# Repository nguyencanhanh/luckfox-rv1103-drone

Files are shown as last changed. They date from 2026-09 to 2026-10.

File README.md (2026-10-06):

# Drone AI trên RV1103 (Luckfox Pico Mini B)

Nguyên mẫu quadcopter dùng **một chip Rockchip RV1103**:
- **Cortex-A7 chạy Linux:** camera, NPU nhận dạng, Wi-Fi, GPS, bộ thu RC.
- **Lõi MCU RISC-V (HPMCU) chạy RT-Thread:** vòng điều khiển bay 1 kHz.

Mục tiêu dự án là trả lời bằng số liệu đo được: **kiến trúc một chip có bay được không**. Nếu không, phương án B là thêm một MCU điều khiển bay rời.

> **Trạng thái (2026-09-27):** chưa bay thật.
> - Linux và MCU đã chạy song song trên board, vòng 1 kHz đã đo.
> - Phần mềm bay chạy đầy đủ trong mô phỏng và lái được trong 3D.
> - Mạch bay LFX_FC_R1 đã thiết kế xong, chưa sản xuất.
> - Chưa có driver cảm biến thật, chưa xuất PWM ra ESC. Motor chưa bao giờ được cấp lệnh.

Sơ đồ khối hệ thống

## Mục lục

- [Trạng thái theo mốc](#trạng-thái-theo-mốc)
- [Kiến trúc](#kiến-trúc)
- [Phần cứng: mạch bay LFX_FC_R2](#phần-cứng-mạch-bay-lfx_fc_r2)
- [Mô phỏng](#mô-phỏng)
- [Bắt đầu nhanh](#bắt-đầu-nhanh)
- [Cấu trúc repo](#cấu-trúc-repo)
- [An toàn](#an-toàn)
- [Tài liệu](#tài-liệu)
- [Nguồn tham khảo](#nguồn-tham-khảo)
- [License](#license)

## Trạng thái theo mốc

| Mốc | Nội dung | Kết quả | Bằng chứng |
|---|---|---|---|
| 01 | Điều tra phần cứng RV1103, HPMCU trong SDK | xong | [RV1103_MCU.md](docs/RV1103_MCU.md), [PERIPHERALS.md](docs/PERIPHERALS.md) |
| 02 | Build firmware Luckfox stock trên macOS | **PASS** | `logs/sdk_build.log`, [MILESTONE1.md](docs/MILESTONE1.md) |
| 03 | Build RT-Thread cho HPMCU | **PASS** | [MCU_BUILD.md](docs/MCU_BUILD.md) |
| 04 | MCU chạy song song Linux, vòng 1 kHz | **PASS trên board**: 2 × 1 000 000 vòng, 0 lỡ chu kỳ; jitter 18,2 µs lúc idle, 116,7 µs khi camera chạy | [REALTIME.md](docs/REALTIME.md) |
| — | Mạch bay LFX_FC_R1 (46 × 46 mm, 4 lớp) | thiết kế xong: ERC 0, DRC 0, 0 nối hở, khớp sơ đồ | [phần cứng](#phần-cứng-mạch-bay-lfx_fc_r1) |
| 05 | Phần mềm bay + mô phỏng SITL + 3D | **77/77 unit test, 10/10 kịch bản bay** (×2 profile cảm biến), kiểm thử bàn phím end-to-end 6/6 | [simulator/README.md](simulator/README.md) |
| 05b | Phần mềm bay chạy trên HPMCU với cảm biến giả (đo thời gian) | build xong (53 KB), **chưa chạy**: board chưa cắm | `tools/run_fc_mcu.sh` |
| 06–07 | Driver SPI + ICM-42688-P trên MCU | chưa làm: cần module IMU để kiểm | |
| 11 | Xuất PWM / DShot, đo bằng logic analyzer | chưa làm, **không gắn cánh** | |
| 12–13 | Điều khiển từ xa: IPC Linux ↔ MCU, `rc-bridge` (ELRS + mạng), trạm mặt đất có camera | **code xong, chuỗi đầy đủ chạy trên Mac 7/7**; build cho board xong, **chưa chạy trên board**; bộ thu ELRS cần chuyển console khỏi UART2 | [ground/README.md](ground/README.md) |
| M3 | Camera → NPU → nhận dạng, Wi-Fi, telemetry | chưa làm | |

Kế hoạch đầy đủ theo thứ tự an toàn ở mục [An toàn](#an-toàn).

## Kiến trúc

| Miền | Chạy gì | Sở hữu phần cứng |
|---|---|---|
| **HPMCU** RISC-V SCR1 297 MHz, `rv32imc` (không FPU), RT-Thread | vòng tốc độ quay 1 kHz, vòng góc 250 Hz, vòng độ cao 100 Hz, trộn motor, ARM / failsafe | SPI0 (IMU, barometer), PWM2 kênh 8–11 (4 ESC) |
| **Cortex-A7** 1,1 GHz, Linux (Buildroot của SDK) | đọc bộ thu RC (CRSF), camera + NPU, điều hướng, LTE + GPS (module Lierda), telemetry Wi-Fi, nạp firmware MCU và Lierda | UART2 (bộ thu RC), UART3 (Lierda: AT, GNSS, nạp firmware), chân 18/20 (RESET/BOOT Lierda), MIPI CSI, USB, SARADC, CRU |
| **DDR chung** 64 MB | MCU chạy ở `0x01800000` (256 KB, đã kiểm chứng); IPC đề xuất ở `0x01840000` | [MEMORY_MAP.md](docs/MEMORY_MAP.md) |

Luồng điều khiển:

```
IMU 1 kHz ─► hiệu chuẩn ─► lọc ─► Mahony (góc) + baro/accel (độ cao)
          ─► PID góc / độ cao ─► PID tốc độ quay ─► trộn quad-X ─► 4 motor (0..1)
tay điều khiển ELRS ─► bộ thu (CRSF 420 kbaud) ─► Linux ─► IPC ─► MCU (lệnh lái, ARM, chế độ)
```

Code bay (`mcu/`) là C99 thuần, chỉ dùng float, không cấp phát động. Cùng một mã nguồn build cho:
- máy Mac (mô phỏng);
- MCU (RT-Thread).

Chỗ đổi duy nhất là nguồn dữ liệu cảm biến:
- `SIM_SENSOR`: cảm biến giả trong mô phỏng;
- `REAL_SENSOR`: driver thật (bước 06–07).

Chi tiết và rủi ro: [ARCHITECTURE.md](docs/ARCHITECTURE.md), [architecture.html](docs/architecture.html).

**Rủi ro lớn nhất của kiến trúc một chip:**

| Rủi ro | Hệ quả |
|---|---|
| HPMCU không có FPU | code bay chạy bằng soft-float; phải đo thời gian thật |
| HAL MCU của RV1106 không có SPI và UART | phải tự viết driver |
| Tải camera làm jitter MCU tăng 6,4 lần | ảnh hưởng độ ổn định vòng điều khiển |
| Tín hiệu RC đi qua Linux | Linux treo là mất RC; MCU phải tự vào failsafe |

## Phần cứng: mạch bay LFX_FC_R2

**Một board 50 × 50 mm** gồm mạch bay cho Luckfox Pico Mini B và module **LTE Cat.1 bis + GNSS** (Lierda NT26-KCN E, khay nano-SIM, 2 cổng U.FL). Thiết kế bằng pipeline KiCad 10 viết bằng script, trong [`hardware/LFX_FC_R2/`](hardware/LFX_FC_R2): `design.py` → sơ đồ → PCB → file sản xuất.

| Mặt trên | Mặt dưới | 3D |
|---|---|---|
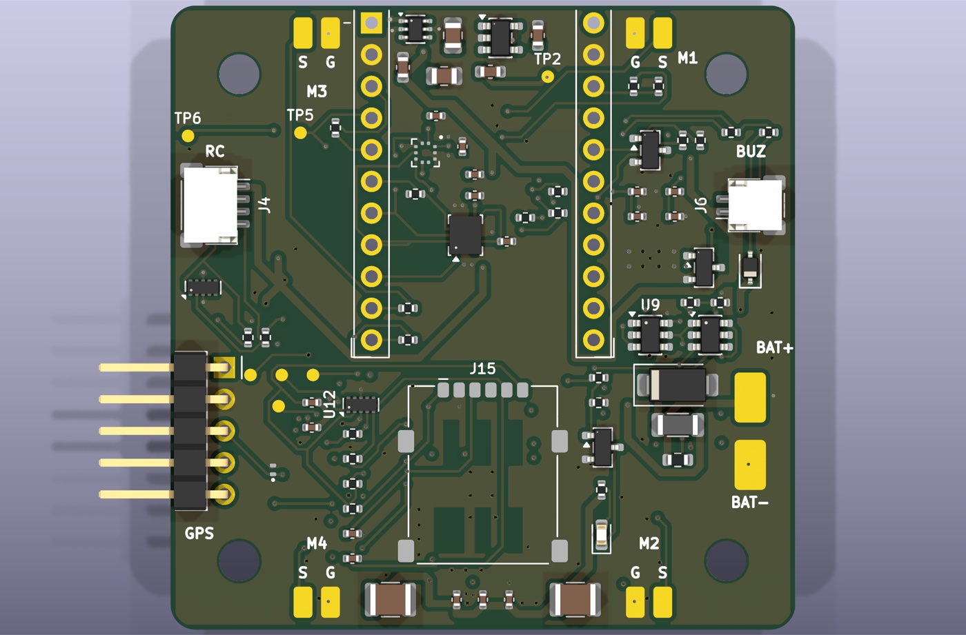
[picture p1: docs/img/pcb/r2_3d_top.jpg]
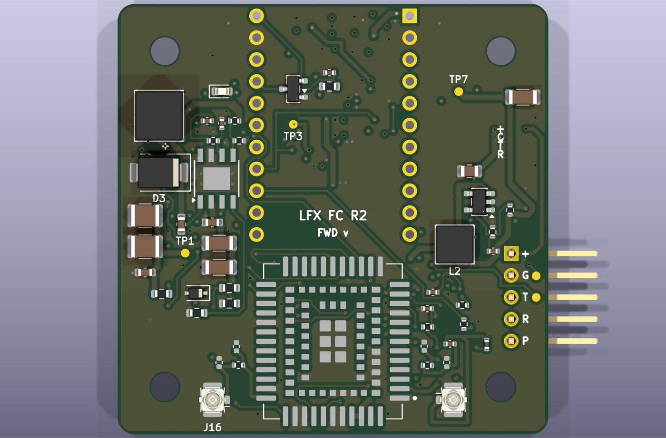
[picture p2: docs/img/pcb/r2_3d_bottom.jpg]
bottom
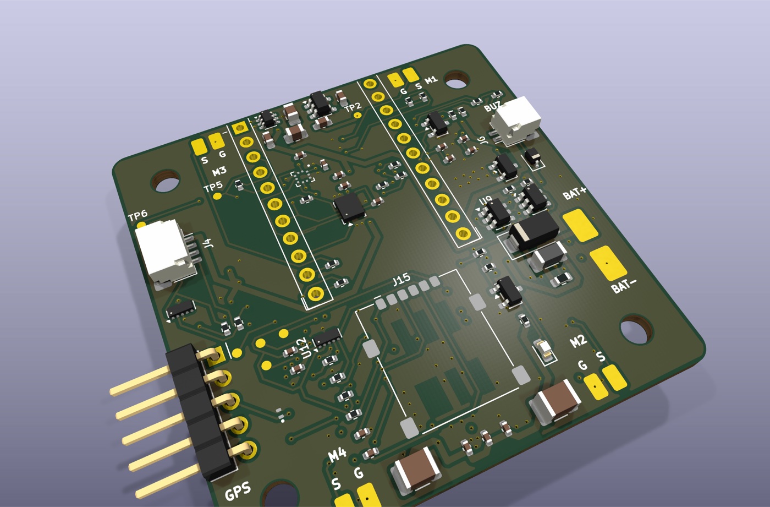
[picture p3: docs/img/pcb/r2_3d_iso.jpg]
iso
|  |  |  |

Module Lierda và đế cắm Luckfox chưa có mô hình 3D trong KiCad nên trên ảnh render chỉ thấy pad của chúng.

**Thông số:**
- **Kích thước:** 50 × 50 mm, 4 lớp: F.Cu tín hiệu / GND / VSYS (+ đảo 3,3 V cảm biến, đảo 3,8 V dưới module LTE, đảo GND dưới đường anten) / B.Cu.
- **Lỗ bắt vít:** 4 lỗ M3, khoảng cách lỗ **39 × 39 mm**, cách mép 5,5 mm.
- **Nguồn vào:** pin 2S–6S, hàn vào pad BAT+ / BAT− (mặt trên, phía trước bên phải).
- **Mạch nguồn:**
  - TVS SMAJ33A và ferrite chặn xung, lọc nhiễu.
  - Buck TPS54360 ra 5 V (theo thiết kế mẫu TI SLVSBB4G), ngưỡng UVLO 6,44 V. Đặt ở mặt dưới dải phải, cách IMU khoảng 15 mm, có lớp GND In1 ở giữa.
  - Diode lý tưởng LM66100 cấp VSYS cho Luckfox; LDO TLV75533 cấp 3,3 V riêng cho cảm biến.
  - Buck TLV62569 hạ +5 V xuống **3,8 V** cho module LTE. VBAT của module chỉ chịu 3,3–4,5 V, nên không lấy thẳng từ pin.
- **Cảm biến trên SPI0:** IMU ICM-42688-P và barometer BMP390, đặt dưới Luckfox; 4 đường SPI của IMU vẽ tay, không dùng via.
- **GPS ngoài (thêm 2026-10-04):** chân 14 (GPIO1_D2) thành **UART5_RX** cho cổng J18; chân chọn chip của barometer chuyển sang chân 15 (GPIO1_D3, MCU điều khiển như GPIO), bỏ chân ngắt dự phòng của IMU (IMU đọc kiểu polling). GNSS trong module Lierda vẫn giữ nguyên.
- **Motor:** 4 cặp pad S/G ở 4 góc cho **4 ESC rời** (PWM8–11, điện trở 47 Ω). Không còn cổng ESC 4-in-1.
- **LTE + GNSS: Lierda NT26-KCN E** ở mặt dưới, nửa trước. Khi đặt mua chọn bản **GPS + BDS**: bản NT26KCNE20GNB trong sổ tay phần cứng chỉ có BeiDou, chân ra giống hệt.
  - UART3 của Luckfox (chân 12/13) đi qua 2 con SN74LVC1T45 để chuyển 3,3 V ↔ 1,8 V. Chip này tự cách ly khi module tắt, vì UART của module không chịu điện áp ngược. Cùng một UART dùng cho lệnh AT, đọc GNSS và nạp firmware (921600 bd).
  - **Luckfox nạp firmware cho Lierda:** chân 18 kéo RESET_N qua MOSFET; chân 20 (GPIO4_C1, bank 1,8 V, cùng mức với module) nối USB_BOOT qua 1 kΩ. Giữ BOOT mức cao rồi reset ≥ 300 ms là module vào chế độ nạp. Có test pad USB (D+/D−/VBUS) để nạp cứu bằng máy tính.
  - Khay **nano-SIM** có nắp bản lề ở mặt trên, giữa phía trước; điện trở 22 Ω, tụ 33 pF, chống ESD TPD4E05U06.
  - 2 cổng U.FL ở 2 góc trước mặt dưới: GNSS bên trái, LTE bên phải. Đường 50 Ω rộng 0,35 mm trên B.Cu, có mạch π để chỉnh phối hợp trở kháng. GNSS cấp nguồn 3,3 V cho anten active; dùng anten thụ động thì bỏ R43.
  - Còi được điều khiển từ chân AGPIO5 (pad 97, ở mép module) của Lierda, vì Luckfox đã hết chân.
  - **Không bật chế độ ngủ của module** (`AT+QSCLK=1`): khi ngủ, VDD_EXT tắt nên bộ chuyển mức cách ly, Luckfox không đánh thức được qua UART.

**Đầu cắm và pad:**

| Cổng | Chân | Ghi chú |
|---|---|---|
| J2 / J3 · pad pin | BAT+ / BAT− | dây XT30 từ pin, cùng dây cấp cho 4 ESC |
| J4 · bộ thu RC ELRS | 1 5 V, 2 GND, 3 TX board → RX bộ thu, 4 RX board ← TX bộ thu | UART2, CRSF; R24 1 kΩ kéo lên để bộ thu không kẹt bootloader |
| J6 · còi | 1 +5 V, 2 còi − (MOSFET đóng ngắt) | gate do AGPIO5 của Lierda điều khiển |
| **J18 · module GPS ATGM336H** | 1 VCC +5 V, 2 GND, 3 TXD module → RX board, 4 RXD (không nối), 5 PPS (không nối) | header 2,54 mm 5 chân nằm ngang ở mép trái, **cùng thứ tự chân với module ATGM336H 5 chân**: thân nhựa trên board, chân cong chìa ra ngoài mép để cắm dây Dupont 5 sợi thẳng sang module (lọt dưới vỏ canopy). UART5 chỉ nhận (chân 14), NMEA 9600 mặc định; RXD và PPS bỏ trống vì Luckfox hết chân. Chống ESD TPD1E05U06 + 33 Ω. +5 V lấy từ buck TPS54360 (cùng nguồn với bộ thu RC J4, đường mặt dưới sát mép trái), nên GPS chỉ có điện khi cắm pin, không chạy khi chỉ cắm USB |
| J7–J14 · pad ESC | S / G ở 4 góc | M1 sau-phải, M2 trước-phải, M3 sau-trái, M4 trước-trái (Betaflight) |
| J15 · nano-SIM | | GCT SIM8060, nắp bản lề |
| J16 · U.FL LTE / J17 · U.FL GNSS | | mặt dưới, 2 góc trước |
| TP1–TP3, TP5, TP6 | +5 V, VSYS, +3V3S, RC_TX, RC_RX | TP5/TP6: xem console khi rút bộ thu |
| TP7–TP13 | +3V8, VDD_EXT 1,8 V, USB D+, USB D−, USB VBUS, DBG TX, DBG RX của Lierda | nạp cứu / xem log module |

**Kiểm tra:** ERC 0, DRC 0 vi phạm / 0 cảnh báo, 0 nối hở, 0 lỗi khớp sơ đồ (`--schematic-parity`).

**Bộ file sản xuất** (Gerber, khoan, BOM, vị trí linh kiện, STEP) do `make_fab.py` tạo ra `fab/`. Thư mục này không lưu trong git.

**Cần làm trước khi đặt hàng:**
- BOM chưa có mã linh kiện cụ thể (MPN).
- Nên chọn xi **ENIG**: IMU, barometer là chip chân LGA và module Lierda là LCC + LGA 109 chân, cần pad phẳng.

### Lắp drone: khung LFX_FRAME_R1, động cơ không chổi than, 4 ESC rời

| Khung (in 3D) | Lắp đủ: khung + board + vỏ + motor + ESC + pin | Nhìn từ trên |
|---|---|---|
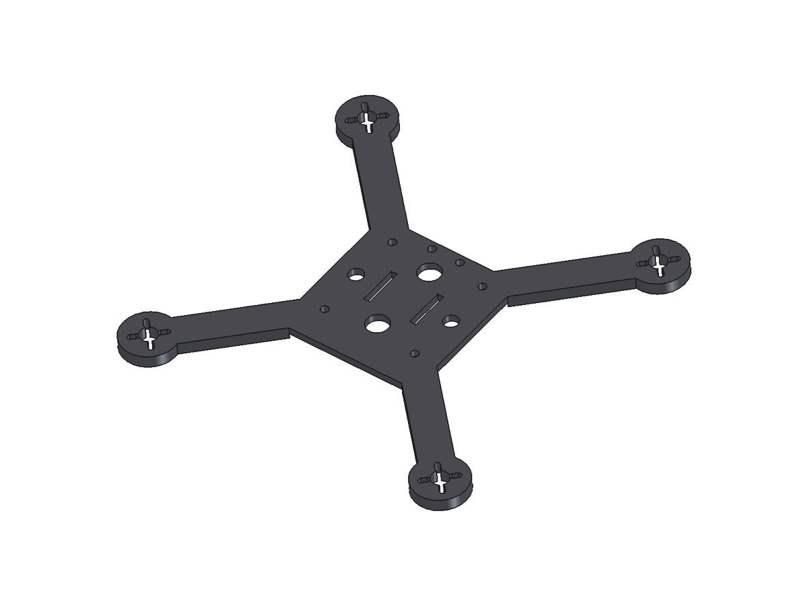
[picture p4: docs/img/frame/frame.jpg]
frame
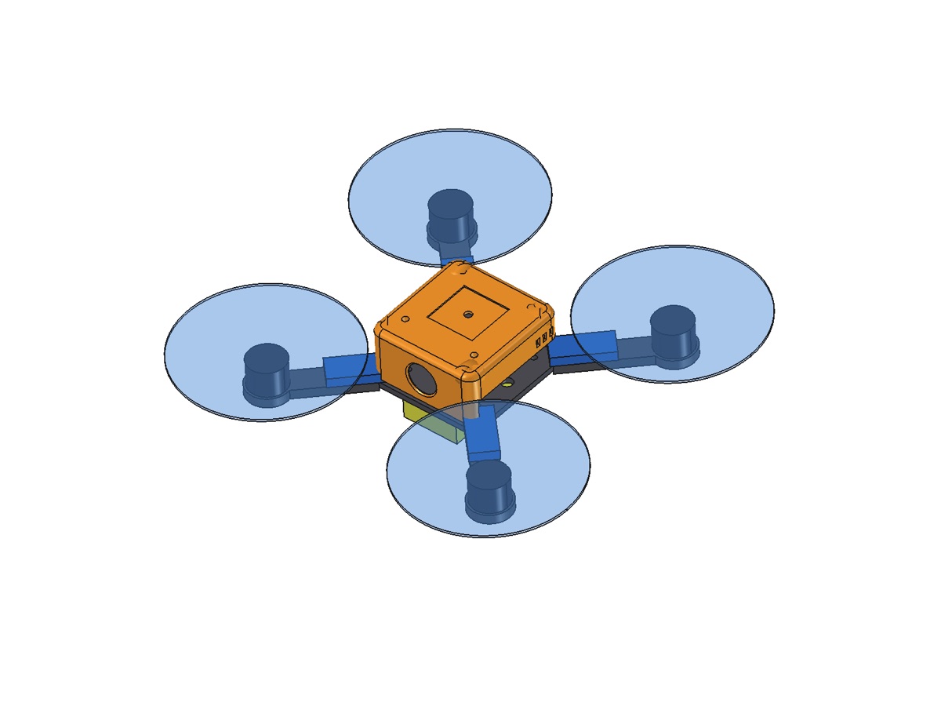
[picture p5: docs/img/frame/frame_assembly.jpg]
assembly
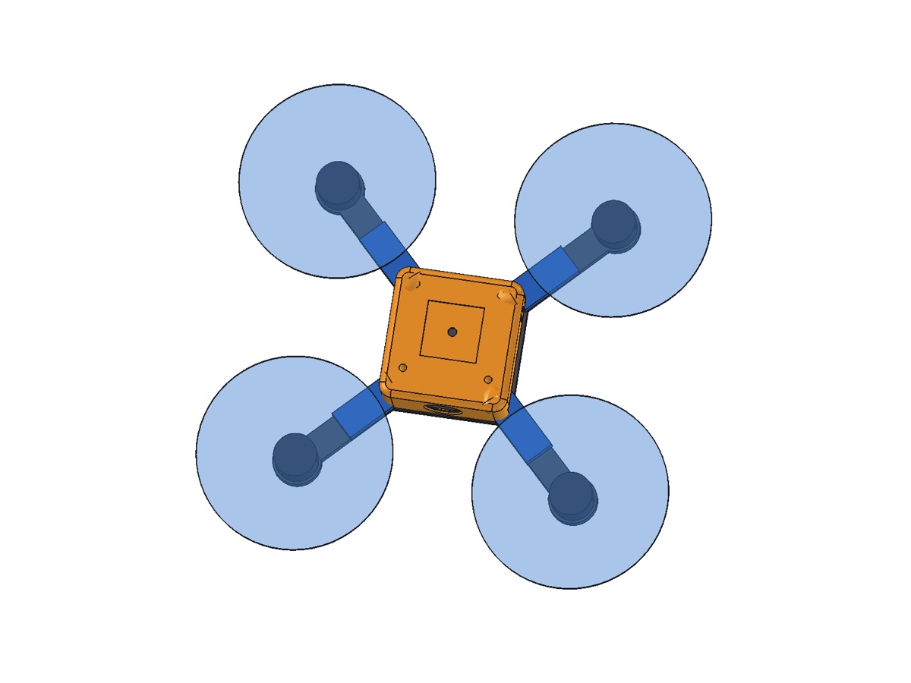
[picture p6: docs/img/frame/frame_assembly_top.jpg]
|  |  |  |

**Khung [`hardware/LFX_FRAME_R1`](hardware/LFX_FRAME_R1)** dựng bằng FreeCAD (script tham số `frame_freecad.py`), in 3D, cho **motor 1503 + cánh 3,5"**:
- Tấm giữa dày 3 mm: board bắt thẳng bằng **4 cột M3 dài 8 mm** vào lỗ 39 × 39, không cần tấm chuyển. Có 2 khe dây buộc pin 15 mm, lỗ khoét giảm nhẹ, 2 lỗ phía sau để buộc ống anten. Mặt dưới tấm giữa phẳng để kê pin.
- 4 tay đòn kiểu X, dày 5 mm, rộng 13 mm. Đế motor Ø22 mm có **rãnh M2 hướng tâm** (bán kính 4,3–6,6 mm): lắp được motor 1503 (4 × M2 theo hình vuông 9 × 9 mm) và các motor có lỗ trên vòng Ø9 mm. Lỗ giữa Ø7 mm cho trục và phe gài.
- **Khoảng cách motor do script tự tìm:** đẩy dần motor ra xa cho tới khi cánh 3,5" (thêm 2 mm dự phòng) không chạm vỏ canopy. Kết quả: motor cách tâm 63 mm theo mỗi trục (đường chéo trục 178 mm), khung 148 × 148 mm.
- 4 ESC buộc dây rút lên tay đòn, nằm ngoài vỏ; pin buộc dưới tấm giữa.
- In: PETG (hoặc PLA-CF), 5 lớp viền, infill 40 %. Khối lượng đặc khoảng 34 g.
- Đổi motor hoặc cánh: sửa `PROP_D`, `MOTOR_D`, `MOTOR_SLOT` ở đầu `frame_freecad.py` rồi chạy lại trong FreeCAD; khoảng cách motor tự tính lại.

**Linh kiện mua thêm:**

| Linh kiện | Gợi ý | Ghi chú |
|---|---|---|
| Motor ×4 | 1503, bản KV dành cho cánh 3,5" và đúng số cell pin (người bán thường ghi "3.5 inch 3S" hoặc "4S") | khoảng 8–9 g/con; 4 × M2 lỗ 9 × 9 mm |
| ESC ×4 | ESC rời 20–30 A, BLHeli_S / BLHeli_32 / AM32, chịu 2–4S | 1503 + cánh 3,5" kéo dòng cao hơn hẳn 1103, ESC 12 A không đủ |
| Cánh | 3,5" (3520 / 3525, 2–3 lá), lỗ trục hợp motor | |
| Pin | LiPo 3S hoặc 4S 450–650 mAh, đầu XT30 | |
| Cột M3 | 4 × 8 mm (khung → board) | |
| Anten | LTE dạng dán (FPC) + GNSS 25 × 25 mm (active 3,3 V hoặc thụ động), đầu U.FL | anten GNSS đặt trong hốc trên nóc vỏ |

**Đấu nối:**
```
Pin 3S/4S ─ XT30 ─┬─ nguồn 4 ESC (đỏ / đen)
                  └─ BAT+ / BAT− (J2 / J3) trên board
ESC n: tín hiệu → pad S, mass tín hiệu → pad G ở góc của motor n
   M1 sau-phải J7/J11 · M2 trước-phải J8/J12 · M3 sau-trái J9/J13 · M4 trước-trái J10/J14
Motor: 3 dây vào ESC; quay ngược chiều thì đổi 2 dây bất kỳ
```
- Board chạy 2S–6S (buck 5 V khởi động từ 6,44 V), nên 3S và 4S đều dư.
- ESC rời không có chân báo dòng, nên chỉ đo được áp pin (ADC_VBAT), không đo được dòng.

**Trọng lượng ước tính** (chưa cân thực tế):
- Board R2 khoảng 16 g, Luckfox + camera khoảng 8 g, 4 ESC khoảng 24 g, 4 motor 1503 khoảng 36 g, khung khoảng 34 g, vỏ khoảng 13 g, cánh khoảng 6 g, anten + ốc + dây khoảng 8 g, pin 4S 450 mAh khoảng 55 g (3S khoảng 40 g).
- Tổng **khoảng 200 g với 4S** (khoảng 185 g với 3S).
- Theo [bảng tra của Oscar Liang](https://oscarliang.com/table-prop-motor-lipo-weight/), cánh 3–3,5" với motor cỡ 1404–1505 trên 3S–4S hợp drone nặng khoảng 150–300 g, nên cấu hình này nằm giữa dải, dư lực. Mình chưa có số đo lực đẩy cụ thể của 1503; hãy xem bảng lực đẩy của đúng mẫu motor khi mua.

### Vỏ in 3D: LFX_CANOPY_R1

| Vỏ | Nhìn xuyên (kiểm tra lắp) | Phía sau |
|---|---|---|
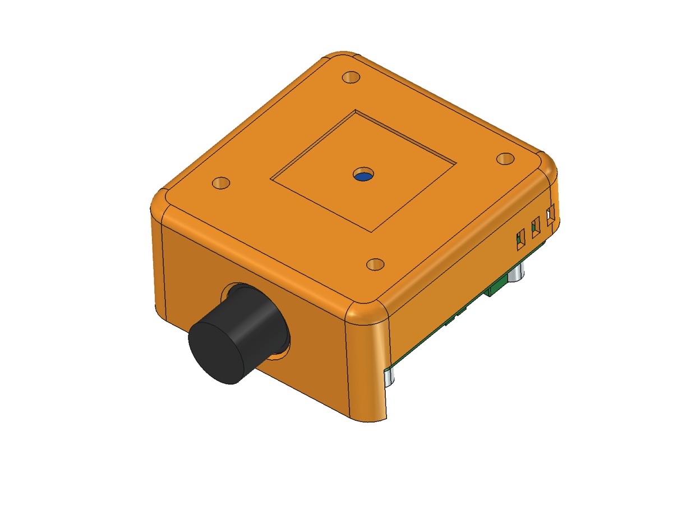
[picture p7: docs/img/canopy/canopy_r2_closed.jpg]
canopy
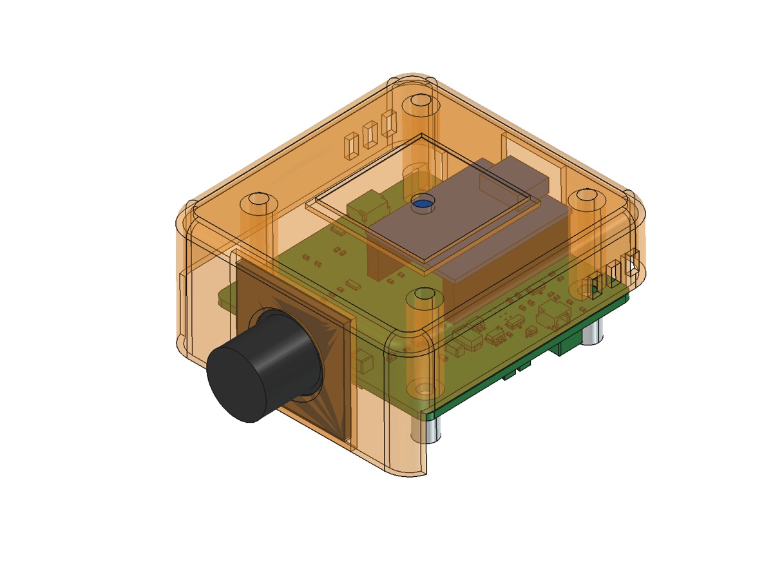
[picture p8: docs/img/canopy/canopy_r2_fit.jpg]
fit
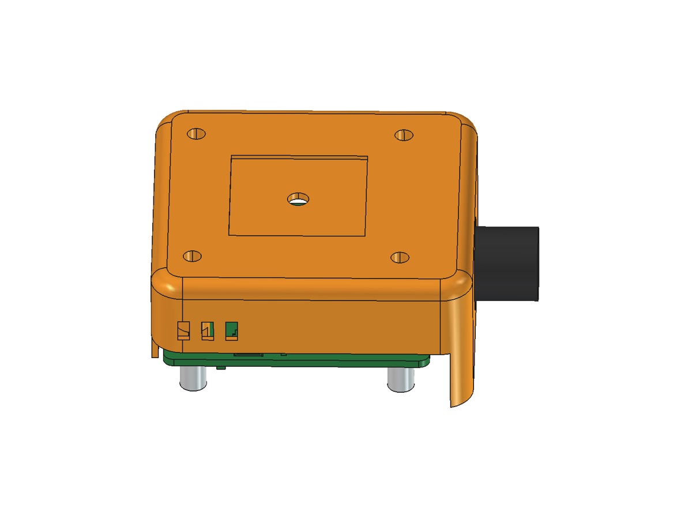
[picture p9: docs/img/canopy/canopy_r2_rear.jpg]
rear
|  |  |  |

Vỏ che board, dựng bằng **FreeCAD 1.1** (script tham số [`canopy_freecad.py`](hardware/LFX_CANOPY_R1/canopy_freecad.py), chạy trong FreeCAD hoặc qua addon [freecad-mcp](https://github.com/neka-nat/freecad-mcp)). Script dựng cả cụm lắp ráp từ file STEP của board (KiCad) cộng khối đại diện cho Luckfox, camera, Lierda, cột đỡ, rồi **kiểm tra va chạm**: không chạm.

- File in: [`canopy.stl`](hardware/LFX_CANOPY_R1/canopy.stl) (và `canopy.step`), 58 × 60 × 29 mm, khoảng 13 g PETG.
- Thành 1,2 mm (3 lớp viền với đầu phun 0,4 mm), bo tròn mọi cạnh, lỗ ống kính vát mép.
- Camera SC3336 áp vào mặt trong thành trước, có gờ định vị 4 phía; cố định bằng băng dính 2 mặt hoặc keo nến.
- Lỗ USB-C phía sau, nên **vẫn cắm cáp nạp code cho Luckfox khi đã đậy vỏ**.
- Hai bên hông để trống phía dưới cho dây RC, còi, ESC, dây pin và cáp U.FL; khe thông gió ngay trên Luckfox.
- Trên nóc có hốc lõm 0,8 mm đặt anten GNSS loại 25 × 25 mm (nằm trên cùng, nhìn thẳng lên trời) và lỗ luồn cáp; mặt nóc vẫn phẳng để in úp.
- 4 trụ rỗng tì xuống board tại 4 lỗ 39 × 39; vít **M3 × 25** xuyên trụ, qua board, vào cột đỡ.
- In: úp nóc xuống bàn in, PETG, không cần support.
- Sửa kích thước: đổi tham số đầu file `canopy_freecad.py` rồi chạy lại trong FreeCAD. File STEP của board xuất bằng `kicad-cli pcb export step` vào `hardware/LFX_CANOPY_R1/step/`.

### Phiên bản cũ

Vẫn giữ trong repo, DRC sạch, nhưng không còn là thiết kế chính:
- [`LFX_FC_R1`](hardware/LFX_FC_R1): mạch bay 46 × 46 mm, cổng ESC 4-in-1 (J1), cổng J5 nối sang board LTE ([ảnh](docs/img/pcb/3d_iso.jpg)).
- [`LFX_LTE_R1`](hardware/LFX_LTE_R1): board LTE 46 × 46 mm xếp tầng trên R1 ([ảnh](docs/img/pcb/lte_3d_iso.jpg)).
- [`LFX_MOUNT_R1`](hardware/LFX_MOUNT_R1): tấm chuyển lỗ 39 × 39 → khung 20 × 20 / 25,5 × 25,5 mm, dùng khi lắp board lên khung mua sẵn thay cho LFX_FRAME_R1 ([ảnh](docs/img/pcb/mount_3d_iso.jpg)).

## Mô phỏng

Toàn bộ phần mềm bay chạy trên máy Mac, lái được bằng bàn phím hoặc tay điều khiển USB. Tín hiệu điều khiển đi qua đúng đường mà bộ thu thật sẽ đi: khung CRSF → bộ đọc CRSF → `fc_tick()`. Chi tiết: [simulator/README.md](simulator/README.md).

| | |
|---|---|
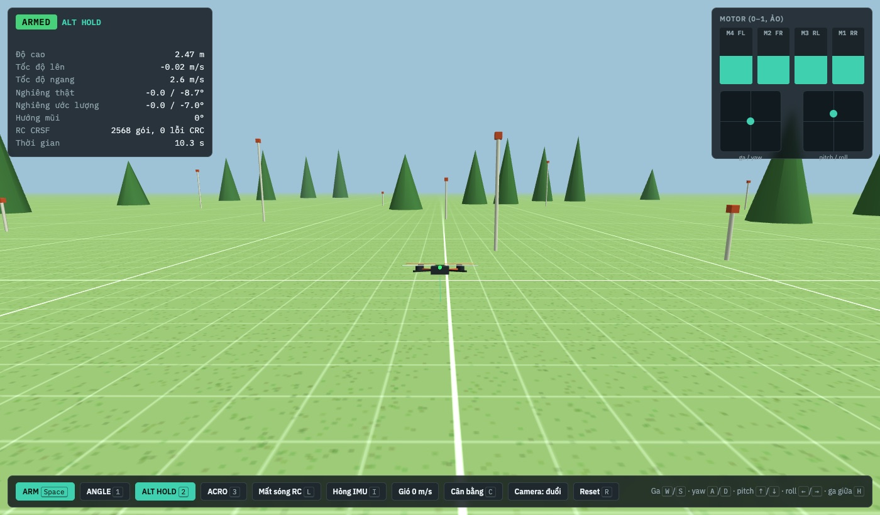
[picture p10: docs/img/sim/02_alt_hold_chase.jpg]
Giữ độ cao
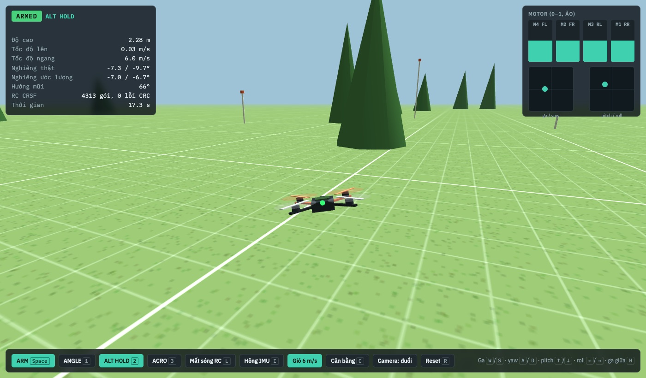
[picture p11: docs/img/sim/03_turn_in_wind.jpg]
Gió
|  **ALT HOLD**, camera đuổi theo |  Vòng trong gió 6 m/s |
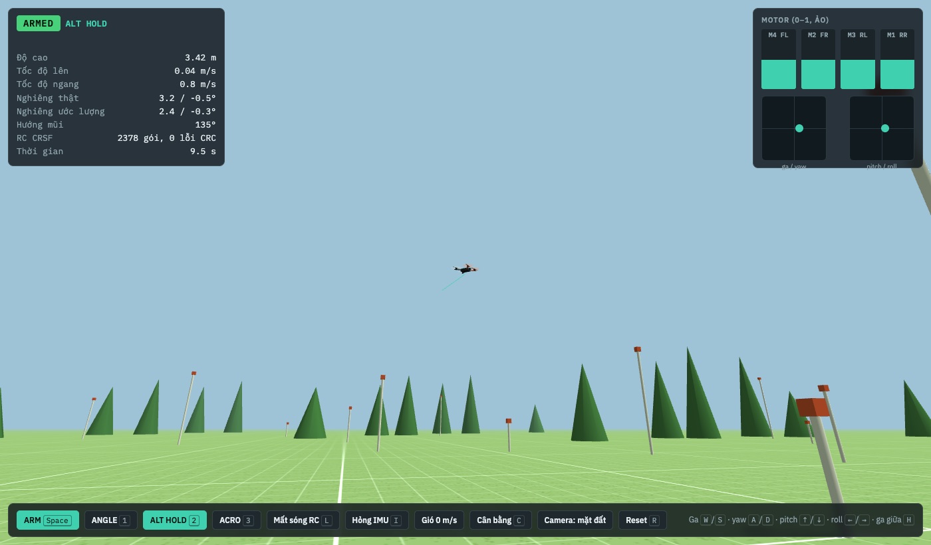
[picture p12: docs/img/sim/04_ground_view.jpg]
Mặt đất
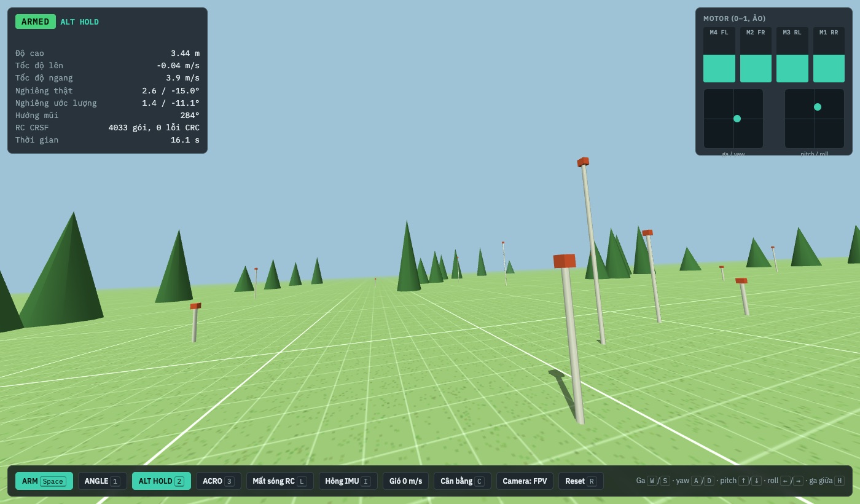
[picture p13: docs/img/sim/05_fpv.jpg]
FPV
|  Người lái đứng dưới đất |  Camera FPV |
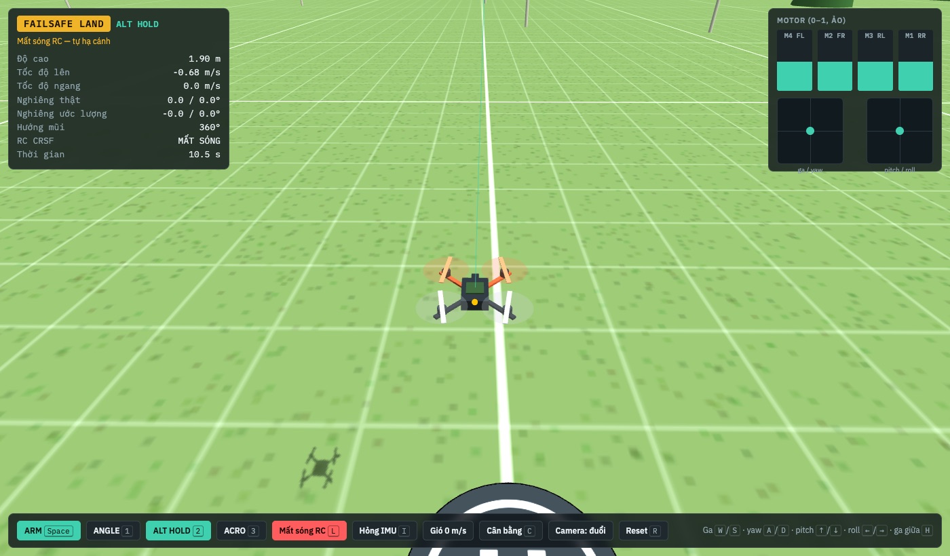
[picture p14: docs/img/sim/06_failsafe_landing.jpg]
Mất sóng
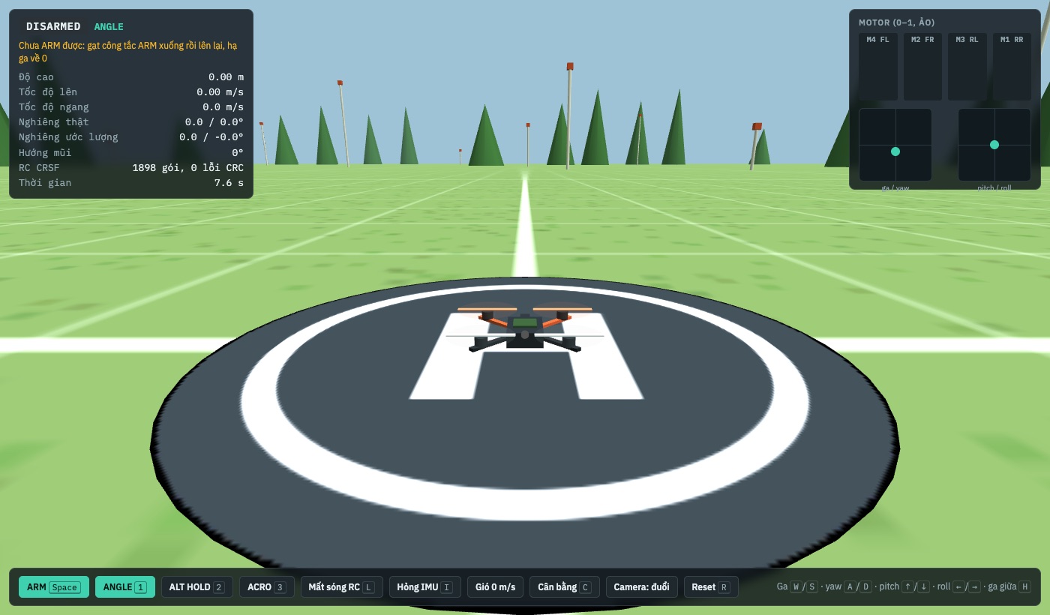
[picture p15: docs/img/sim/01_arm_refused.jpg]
Từ chối ARM
|  **Mất sóng RC** → tự hạ cánh |  **Từ chối ARM** khi ga chưa về 0 |

Dữ liệu từ chính các kịch bản kiểm thử (`tools/plot_sim.py`):

Mất sóng RC

Bước nghiêng

**Kết quả kiểm thử** (`make -C simulator test`):

| Kịch bản | Kết quả |
|---|---|
| giữ độ cao 10 s | sai số tối đa 0,25 m, nghiêng 0,2°, ước lượng góc sai 0,09° rms |
| bước nghiêng 15° | đạt 90 % trong 0,27 s, vọt lố 12 % |
| mất sóng RC ở 4 m | giữ thăng bằng sau 0,26 s, tự hạ sau 1,26 s, chạm đất và tự tắt motor, không rơi |
| IMU hỏng giữa trời | tắt motor sau 20 ms |
| gió 4,5 m/s + giật 2 m/s | độ cao sai < 0,3 m, nghiêng < 4° |
| lật 360° ở ACRO | đạt 418 °/s (yêu cầu 400), tự cân bằng lại, ước lượng góc vẫn đúng |
| bật ALT HOLD khi đang lên 9 m/s | phanh rồi khóa độ cao, sau 3 s lệch < 0,2 m |

**Giới hạn đã biết:**
- **Khung drone là giả định** (0,6 kg, 225 mm, 6 N/motor). Các hệ số PID chỉ là điểm xuất phát.
- **Chưa có GPS nên không giữ được vị trí.** Khi drone tăng tốc hoặc vào cua, góc ước lượng lệch 2–5°, vì accelerometer không phân biệt được nghiêng với gia tốc.
- **Thời gian chạy đo trên Mac không đại diện cho MCU.** Phải đo trên board.

## Điều khiển từ xa và camera

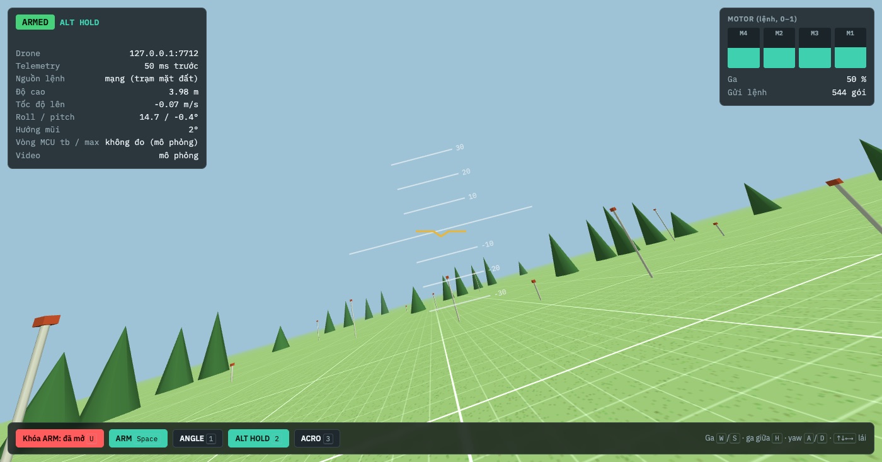
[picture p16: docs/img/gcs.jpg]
Trạm mặt đất


Trạm mặt đất trên Mac: video camera, đường chân trời nhân tạo, telemetry, lái bằng bàn phím hoặc tay điều khiển USB.
Lệnh đi qua UDP tới `rc-bridge` trên Linux của drone, rồi qua RAM chung tới code bay trên MCU. Bộ thu ELRS (nếu có)
luôn được ưu tiên. Camera là `rkipc` sẵn có (RTSP `/live/1`, H.265 704×576). Chi tiết, an toàn, giới hạn:
[ground/README.md](ground/README.md).

## Bắt đầu nhanh

Máy phát triển: macOS (Apple Silicon), Docker qua OrbStack, `adb`, KiCad 10 (chỉ cần cho phần cứng).

**Mô phỏng** (chỉ cần `cc` và `python3`):

```sh
make -C simulator test       # unit test + kịch bản bay
make -C simulator run        # rồi mở http://127.0.0.1:8777
```

Lái thử: `C` hiệu chuẩn → `Space` ARM → giữ `W` cho cất cánh → `2` giữ độ cao → `H` ga giữa → phím mũi tên để lái.
Hạ cánh: vẫn ở `2` (ALT HOLD), giữ `S` (xuống tối đa 1 m/s), chạm đất thì `Space`. Hạ ga về 0 ở chế độ `1` là rơi tự do. Drone rơi thì bấm `R`.
Thử lỗi: `L` cắt sóng RC, `I` hỏng IMU, `G` gió.
Tay điều khiển EdgeTX/ELRS cắm USB (chế độ joystick) được nhận tự động.

**Source SDK (Linux kernel, U-Boot, Buildroot, RT-Thread):** 14 GB, nằm trong Docker volume `luckfox-src`
(ổ ảo của OrbStack phân biệt hoa/thường, ổ SSD thì không). `sdk/` trong repo là symlink tới đó, chỉ mở
được khi Docker engine đang chạy (`orb start`), và không nằm trong git:

```sh
ln -s ~/OrbStack/docker/volumes/luckfox-src/luckfox-pico sdk   # tạo lại nếu thiếu
ls sdk/sysdrv/source/          # kernel  uboot  buildroot  mcu
```

**Firmware Luckfox (Linux):**

```sh
./run.sh build               # build SDK trong Docker (volume luckfox-src), ảnh ra images/
./run.sh flash               # nạp qua ADB
./run.sh connect             # SSH root@172.32.0.93 qua USB-ECM
```

**Firmware MCU:**

```sh
tools/build_mcu.sh luckfox_mini-M1-NONE   # Milestone 1: vòng 1 kHz đo jitter
tools/build_mcu.sh luckfox_mini-FC-NONE   # phần mềm bay + cảm biến giả trên MCU
tools/build_linux_tools.sh                # mcu-tool (nạp / log / dừng MCU từ Linux)
tools/run_fc_mcu.sh 60                    # nạp lên board, chạy 60 s, lưu log vào logs/
```

`run_fc_mcu.sh` tự kiểm tra vùng nhớ MCU (reserved-memory `mcu@1800000`) trước khi nạp. Sai thì dừng, không nạp. Quy trình chi tiết: [MILESTONE1.md](docs/MILESTONE1.md), [MCU_BUILD.md](docs/MCU_BUILD.md).

**Mạch bay** (KiCad 10; `KP` = python đi kèm KiCad):

```sh
hardware/fetch_vendor.sh            # STEP + sơ đồ Luckfox + datasheet (không lưu trong repo)
cd hardware/LFX_FC_R1
KP=/Applications/KiCad/KiCad.app/Contents/Frameworks/Python.framework/Versions/3.9/bin/python3.9
export FREEROUTING_JAR=$HOME/freerouting-1.9.0.jar
python3 scripts/gen_lib.py && python3 scripts/gen_sch.py          # thư viện + sơ đồ nguyên lý
$KP scripts/gen_pcb.py && $KP scripts/route_critical.py           # đặt linh kiện, đi dây quan trọng
FR_ATTEMPTS=3 $KP scripts/route_pcb.py && $KP scripts/route_maze.py && $KP scripts/clean_stubs.py
python3 scripts/make_fab.py && python3 scripts/make_images.py     # file sản xuất, DRC, ERC, ảnh
```

Nguồn gốc duy nhất của mạch là `scripts/design.py`. Không sửa tay file `.kicad_sch` / `.kicad_pcb`.

**Ảnh cho README:** `tools/sim_screenshots.sh` (cần Google Chrome) và `python3 tools/plot_sim.py`.

## Cấu trúc repo

```
docs/                 kiến trúc, bằng chứng phần cứng, bản đồ bộ nhớ, kết quả đo, ảnh
hardware/LFX_FC_R2/   mạch bay + LTE/GNSS trên 1 board: scripts/ (design.py → sơ đồ → PCB → file sản xuất), sch/
hardware/LFX_FRAME_R1/   khung in 3D (FreeCAD: frame_freecad.py → frame.stl / .step)
hardware/LFX_CANOPY_R1/  vỏ in 3D (FreeCAD: canopy_freecad.py → canopy.stl / .step)
hardware/LFX_FC_R1/   bản cũ 46 × 46 mm; lib/ là thư viện symbol / footprint LFX dùng chung
hardware/LFX_LTE_R1/, LFX_MOUNT_R1/   bản cũ: board LTE xếp tầng, tấm chuyển lỗ bắt vít
hardware/datasheets/  danh sách datasheet và link chính thức (PDF tải bằng hardware/fetch_vendor.sh)
mcu/
  common/             toán vector / quaternion (float)
  sensors/            giao diện cảm biến, bộ lọc, hiệu chuẩn gyro
  estimator/          Mahony, ước lượng độ cao
  control/            PID, bộ điều khiển tầng
  mixer/              trộn quad-X
  failsafe/           ARM, failsafe, phát hiện rơi
  fc/                 fc_step() / fc_tick(), tham số mặc định
  link/               nhận lệnh / gửi telemetry qua IPC
  tests/              unit test
  bsp/                board RT-Thread: M1 (đo 1 kHz), FC (phần mềm bay trên MCU)
shared/
  ipc/                layout bộ nhớ chung MCU ↔ Linux, vòng đệm fc_ipc
  rc/                 CRSF, ánh xạ kênh RC
simulator/            mô hình quad, cảm biến giả, kịch bản, server + trang 3D
linux/                phía Linux: mcu-tool (nạp / log / dừng MCU), rc-bridge (điều khiển từ xa), DTS
ground/               trạm mặt đất: gcs.py + trang web (video, telemetry, lái), kiểm thử cả chuỗi
tools/                script build / nạp / chụp ảnh
run.sh                build → flash → connect firmware Luckfox
sdk -> ~/OrbStack/…   symlink tới SDK Luckfox trong Docker volume (không vào git)
```

## An toàn

Thứ tự phát triển bắt buộc (plan mục 29), không bỏ bước:

1. mô phỏng phần mềm ✅
2. mô phỏng trên MCU (đã build, chờ chạy)
3. IMU trên bàn
4. PWM, đo bằng logic analyzer
5. ESC không cánh
6. motor không cánh
7. buộc dây thử có kiểm soát
8. mới tính tới bay

Quy tắc trong code:
- Luôn khởi động ở **DISARMED**. Không bao giờ tự ARM.
- Muốn ARM phải: gạt công tắc xuống rồi lên lại, ga ở mức 0, còn sóng RC, IMU sống, đã hiệu chuẩn, drone đang nằm thẳng.
- Mất sóng: giữ thăng bằng 1 s, rồi tự hạ cánh, rồi tự tắt motor. Mất IMU: tắt motor ngay.

Quy tắc làm việc:
- **Không đụng ESC hay motor khi chưa có sự đồng ý rõ ràng.**
- Mọi số liệu phải ghi nguồn (file, dòng, datasheet, log). Chưa kiểm chứng thì ghi `UNKNOWN — NEED VERIFICATION`.

## Tài liệu

| File | Nội dung |
|---|---|
| [ARCHITECTURE.md](docs/ARCHITECTURE.md) · [architecture.html](docs/architecture.html) | phần cứng đã xác minh, chia việc Linux / MCU, rủi ro, phương án B |
| [RV1103_MCU.md](docs/RV1103_MCU.md) | bằng chứng về HPMCU từ SDK |
| [PERIPHERALS.md](docs/PERIPHERALS.md) | ngoại vi, sơ đồ chân, bộ thu RC trên UART2 |
| [MEMORY_MAP.md](docs/MEMORY_MAP.md) | vùng nhớ MCU, log, IPC |
| [IPC.md](docs/IPC.md) | trao đổi Linux ↔ MCU |
| [REALTIME.md](docs/REALTIME.md) | kết quả đo vòng 1 kHz |
| [MILESTONE1.md](docs/MILESTONE1.md) | quy trình build / nạp / kiểm tra Milestone 1 |
| [MCU_BUILD.md](docs/MCU_BUILD.md) | build firmware MCU |
| [simulator/README.md](simulator/README.md) | mô phỏng: điều khiển, kịch bản, nguồn số liệu, giới hạn |

## Nguồn tham khảo

- SDK Luckfox: [LuckfoxTECH/luckfox-pico](https://github.com/LuckfoxTECH/luckfox-pico) @ `824b817f`
- Datasheet (không lưu trong repo, tải bằng `hardware/fetch_vendor.sh`, nguồn ở [hardware/datasheets/README.md](hardware/datasheets/README.md)): ICM-42688-P DS-000347 v1.7, BMP390, TPS54360 (SLVSBB4G), LM66100, TLV755P
- CRSF: [tbs-fpv/tbs-crsf-spec](https://github.com/tbs-fpv/tbs-crsf-spec/blob/main/crsf.md) · ExpressLRS: [Receiver Wiring](https://www.expresslrs.org/quick-start/receivers/wiring-up/) · [betaflight#12398](https://github.com/betaflight/betaflight/issues/12398)
- Mahony, Hamel, Pflimlin, *Nonlinear Complementary Filters on the Special Orthogonal Group*, IEEE TAC 2008 · [ahrs docs](https://ahrs.readthedocs.io/en/latest/filters/mahony.html)
- Động học quadcopter: [Gibiansky](https://andrew.gibiansky.com/blog/physics/quadcopter-dynamics/) · [PX4 SITL motor model](https://github.com/PX4/sitl_gazebo/issues/110) · Faessler, Franchi, Scaramuzza, *Differential Flatness of Quadrotor Dynamics Subject to Rotor Drag*, RA-L 2018

## License

| Phần | License |
|---|---|
| Phần mềm: `mcu/`, `shared/`, `simulator/`, `linux/`, `tools/`, `run.sh`, tài liệu | [MIT](LICENSE) |
| Thiết kế phần cứng: `hardware/` (sơ đồ, PCB, thư viện LFX, script sinh mạch) | [CERN-OHL-P v2](hardware/LICENSE) |

Ngoại lệ: file mang header bản quyền riêng giữ nguyên license của chúng.
- `mcu/bsp/*/board.h`, `iomux.h`: Rockchip, Apache-2.0.
- `linux/dts/*.dts`: dựa trên DTS của Luckfox, GPL-2.0+ OR MIT.

SDK Luckfox / Rockchip, datasheet và tài liệu của Luckfox **không** nằm trong repo; tải từ nguồn chính thức.

Dự án thử nghiệm, **không có bảo đảm**. Drone có cánh quay là thiết bị nguy hiểm: làm theo đúng thứ tự ở mục [An toàn](#an-toàn).

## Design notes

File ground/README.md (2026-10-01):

# Điều khiển từ xa + camera

Trạm mặt đất bay drone mô phỏng

```
trạm mặt đất (Mac, ground/gcs.py + trình duyệt)
   │  lệnh lái: khung CRSF qua UDP 7700, 50 Hz          ▲ telemetry CRSF 20 Hz      ▲ video MJPEG
   ▼                                                     │                           │
rc-bridge (Linux trên drone, linux/rc-bridge) ──────────┘                    ffmpeg ◄── RTSP H.265
   │  ưu tiên: bộ thu ELRS (UART2, CRSF 420000) > mạng > không gì (= failsafe)        rkipc (camera SC3336)
   ▼  vòng đệm fc_ipc trong RAM chung (trang 4 KB tại MCU_IPC_BASE = 0x0183F000)
MCU: fc_link → fc_step (code bay) → telemetry ngược lên
```

| Thành phần | File | Chạy ở đâu |
|---|---|---|
| Kênh Linux ↔ MCU | `shared/ipc/fc_ipc.{h,c}`: 2 vòng đệm SPSC, seq, CRC-16, xử lý cache phía MCU | MCU, Linux, máy tính |
| Phía MCU | `mcu/link/fc_link.{h,c}`: RC → `rc_map` → `fc_rc_input`, telemetry 50 Hz | MCU, mô phỏng |
| Phía Linux | `linux/rc-bridge/`: chọn nguồn lệnh, chuyển tiếp, telemetry về tay điều khiển và trạm mặt đất | board (ARM), máy tính |
| Trạm mặt đất | `ground/gcs.py` + `ground/web/index.html` | Mac |
| Camera | `rkipc` có sẵn trong firmware: RTSP cổng 554, `/live/0` 2304×1296 và `/live/1` 704×576 H.265 (`rkipc/common/rtsp/rtsp.c:23`, `src/rv1103_ipc/video/video.c:38-40`, `rkipc-300w.ini`) | board |

## Thử ngay trên Mac (drone mô phỏng)

```sh
make -C simulator && make -C linux/rc-bridge
python3 simulator/server.py --ipc /tmp/lfx_ipc.bin              # "MCU": code bay + vật lý
linux/rc-bridge/build/rc-bridge --shm /tmp/lfx_ipc.bin          # "Linux của drone"
python3 ground/gcs.py --drone 127.0.0.1 --video sim             # trạm mặt đất
# mở http://127.0.0.1:8780
```

Cả 3 lệnh chạy ở 3 cửa sổ terminal riêng. Video lúc này là góc nhìn FPV của mô phỏng.

## Trên board thật (khi cắm board)

```sh
tools/build_mcu.sh luckfox_mini-FC-NONE && tools/build_linux_tools.sh   # một lần
tools/run_drone_remote.sh                                               # nạp MCU, chạy rc-bridge
python3 ground/gcs.py --drone 172.32.0.93 --video rtsp://172.32.0.93/live/1
```

Lúc này MCU vẫn chạy với **cảm biến giả** (chưa có driver IMU) và **không có đầu ra motor**. Nghĩa là đang thử
đường lệnh, telemetry và camera thật, không phải bay thật. `tools/run_drone_remote.sh stop` để dừng.

## Lái

| Phím | Việc |
|---|---|
| `U` | mở / đóng **khóa ARM** của trạm mặt đất (đóng thì kênh ARM luôn thấp) |
| `Space` | công tắc ARM |
| `1` `2` `3` | ANGLE / ALT HOLD / ACRO |
| `W` `S`, `H` | ga, ga giữa |
| `A` `D`, `↑↓←→` | xoay, lái |

Tay điều khiển EdgeTX/ELRS cắm USB (chế độ joystick) được nhận tự động. Thứ tự kênh AETR, AUX1 = ARM, AUX2 = chế độ.

## An toàn

- **Trang trạm mặt đất đóng hoặc treo:** server ngừng gửi lệnh sau 0,2 s. Drone tự failsafe: giữ thăng bằng → tự hạ cánh
  → tắt motor (`ground/test_chain.py` kiểm tra đúng điều này).
- **Thời gian cho phép hạ cánh tính theo độ cao lúc mất sóng.** Lỗi cũ: giới hạn cứng 20 s sẽ tắt motor giữa trời
  nếu mất sóng ở trên khoảng 14 m. Đã sửa, có kịch bản `rc_loss_high` (30 m) chặn lỗi này.
- **Bộ thu ELRS luôn được ưu tiên hơn mạng.** `rc-bridge` không bao giờ lặp lại lệnh cũ; im lặng chính là tín hiệu failsafe.
- **Mở khóa ARM chỉ cho phép, không tự ARM.** Code bay vẫn đòi đủ điều kiện: gạt công tắc, ga 0, đã hiệu chuẩn,
  drone nằm thẳng.

## Kiểm thử

```sh
python3 ground/test_chain.py      # trạm mặt đất → UDP → rc-bridge → IPC → code bay → telemetry
python3 ground/crsf.py            # CRSF Python (CRC-8/DVB-S2, đóng gói kênh)
```

Kết quả 2026-10-01: 7/7. Gồm: telemetry về, nguồn lệnh "mạng", khóa ARM chặn đúng, ARM sau khi mở khóa, cất cánh
và giữ độ cao, độ cao trong telemetry khớp, trạm mặt đất im lặng thì drone failsafe → hạ cánh → tắt motor.
Video: đoạn H.265 704×576 25 fps (giống `/live/1`) ra trình duyệt đủ 25 hình/giây.

## Giới hạn hiện tại (chưa kiểm chứng trên board)

- **Mạng:** hiện chỉ có cáp USB (USB-ECM, 172.32.0.93), tức là "từ xa" bằng dây. Muốn Wi-Fi thì phải chuyển USB-C sang host
  và cắm USB Wi-Fi; khi đó mất ADB/ECM. **UNKNOWN.**
- **Điều khiển từ xa thật sự (tầm xa)** phải qua bộ thu ELRS. Cần chuyển console Linux khỏi UART2 (sửa DTS, nạp lại
  firmware), rồi chạy `rc-bridge --devmem --uart /dev/ttyS2`. Tên thiết bị `/dev/ttyS2` lúc đó: UNKNOWN.
- **Độ trễ video RTSP → trình duyệt chưa đo.** Tắt bộ đệm (`-fflags nobuffer`) có dùng; `-flags low_delay` làm hỏng
  giải mã HEVC trong lần thử offline nên chưa bật.
- **Khung pin CRSF (0x08) chưa gửi:** đơn vị điện áp trong đặc tả chưa xác nhận được.
- **Telemetry RSSI/LQ của ELRS** chỉ có khi bộ thu gửi LINK_STATISTICS.

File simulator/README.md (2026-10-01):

# Mô phỏng bay (SITL) — 05-simulator

Chạy toàn bộ phần mềm bay trên máy Mac, không cần board, không cần motor.
Code bay trong `mcu/` (ước lượng góc, PID, mixer, failsafe) và `shared/rc/` (CRSF)
**chính là code sẽ build cho MCU**. Simulator chỉ thay phần cảm biến bằng `SIM_SENSOR`
và thay motor bằng mô hình vật lý (plan mục 26).

```
tay điều khiển / bàn phím ─► khung CRSF (như bộ thu ELRS gửi) ─► độ trễ link + Linux + IPC
    ─► crsf_parser ─► rc_map ─► fc_tick()  ◄── SIM_SENSOR (ICM-42688-P + BMP390 giả lập)
                                   │
                                   ▼ 4 số 0..1 (motor ảo)
                             mô hình quad 6 bậc tự do (4 kHz) ─► hiển thị 3D
```

ALT HOLD trong 3D

Thêm ảnh và biểu đồ: [README gốc](../README.md#mô-phỏng). Tạo lại ảnh: `tools/sim_screenshots.sh`,
biểu đồ: `python3 tools/plot_sim.py`.

## Chạy

```sh
make -C simulator            # build: unit test, sim_cli, libsim
make -C simulator test       # 77 unit test + 10 kịch bản bay × 2 profile cảm biến
make -C simulator e2e        # bấm phím thật vào trang 3D qua Chrome headless: cất cánh, bay, hạ cánh
make -C simulator run        # mở http://127.0.0.1:8777 để lái trong 3D
```

Chỉ cần `cc` và `python3` (thư viện chuẩn). Trang 3D tải three.js r128 từ cdnjs.

## Lái trong 3D

| Phím | Việc |
|---|---|
| `Space` | công tắc ARM (bật/tắt) |
| `1` / `2` / `3` | ANGLE (tự cân bằng) / ALT HOLD (giữ độ cao) / ACRO |
| `W` `S` | ga lên / xuống (giữ nguyên khi nhả, như cần ga thật) · `H` = ga giữa |
| `A` `D` | xoay mũi trái / phải |
| `↑` `↓` `←` `→` | chúi tới / lui, nghiêng trái / phải |
| `L` | cắt sóng RC → thử failsafe |
| `I` | hỏng IMU |
| `G` | gió 0 / 3 / 6 / 9 m/s |
| `C` | hiệu chuẩn cân bằng (drone đứng yên trên mặt phẳng) |
| `V` | camera: đuổi theo / người đứng dưới đất / FPV |
| `R` | reset |

Cách bay thử: `C` → chờ hết dòng "đang hiệu chuẩn" → `Space` (ARM) → giữ `W` tới ~0,65 cho
cất cánh → `2` (ALT HOLD) → `H` (ga giữa = giữ độ cao) → lái bằng các phím mũi tên.
Hạ cánh: ở ALT HOLD giữ `S` (xuống tối đa 1 m/s), chạm đất thì `Space`. Ở ANGLE mà hạ ga về 0 là rơi tự do, chạm
đất > 4 m/s thì bị tính là rơi: bấm `R` để đặt lại. Dòng gợi ý ở giữa phía trên màn hình luôn nói bước tiếp theo.

**Tay điều khiển thật:** radio EdgeTX / ELRS cắm USB ở chế độ joystick sẽ hiện ra như gamepad.
Trang tự nhận; bảng "Tay điều khiển USB" cho chọn trục và đảo chiều (mặc định AETR: trục 0–5
= roll, pitch, ga, yaw, ARM, chế độ). Mở thêm `http://127.0.0.1:8777/?watch` ở màn hình khác để
chỉ xem.

## Kịch bản tự kiểm (`build/sim_cli`)

| Kịch bản | Kiểm tra |
|---|---|
| `arm_refusal` | công tắc ARM bật sẵn lúc khởi động không arm; ga cao không arm; motor = 0 |
| `hover` | giữ độ cao 10 s: sai số < 0,3 m, nghiêng < 3°, ước lượng góc sai < 1° rms |
| `angle_step` | nghiêng 15°: 90 % trong < 0,4 s, vọt lố < 20 % |
| `yaw` | yaw đúng chiều (mũi sang phải), tốc độ đúng ±20 % |
| `rc_loss` | mất sóng: giữ thăng bằng sau 0,25 s, tự hạ sau 1 s nữa, chạm đất rồi tự disarm, không rơi |
| `imu_fail` | IMU chết giữa trời: tắt motor trong 20 ms |
| `wind` | gió 4,5 m/s + giật 2 m/s: độ cao sai < 1 m, nghiêng < 20° |
| `acro_flip` | lật 360° ở ACRO (400 °/s) rồi về ANGLE: tự cân bằng lại, ước lượng góc vẫn đúng |
| `rc_loss_high` | mất sóng ở 30 m: hạ cánh tới đất rồi mới tắt motor (trước đây tắt giữa trời sau 20 s) |
| `alt_engage` | bật ALT HOLD khi đang lao lên 9 m/s: phanh rồi mới khóa độ cao, không vọt lên rồi tụt xuống |

`build/sim_cli --csv log.csv hover` ghi log 100 Hz; `--vib` thêm rung khung (giả định).

**Làm drone cho trạm mặt đất:** `python3 server.py --ipc /tmp/lfx_ipc.bin` nhận lệnh qua IPC từ
`linux/rc-bridge`, giống MCU thật; xem [ground/README.md](../ground/README.md).

**Độ mượt:** mở trang với `?debug` để xem bảng đo: thời gian khung hình, nhịp trạng thái đến, số khung
drone đứng hình khi đang bay. Server gửi đúng một trạng thái mỗi bước mô phỏng (50 Hz), trang vẽ lùi
80 ms và nội suy giữa hai trạng thái, nên màn hình 60 Hz vẫn mượt. Đo trên Apple M4: trước khi sửa
54 % khung hình drone đứng yên rồi nhảy cóc, sau khi sửa 0,6 % (chỉ lúc mới mở trang).
`node simulator/probe_debug.mjs "http://127.0.0.1:8777/?watch&debug" 10 /tmp/p.png gpu` đọc bảng đó qua Chrome.

## Nguồn số liệu

| Thứ | Giá trị | Nguồn |
|---|---|---|
| Nhiễu gyro | 0,0028 °/s/√Hz | ICM-42688-P DS-000347 v1.7, tr. 11 |
| Lệch zero gyro | ±0,5 °/s | cùng bảng |
| Nhiễu accel | 65 (x, y) / 70 (z) µg/√Hz | cùng datasheet |
| Lệch zero accel | ±20 mg | cùng datasheet |
| Nhiễu áp suất | 2,0 Pa rms (standard, IIR tắt) | BMP390 datasheet, bảng 8 |
| Khung CRSF, CRC 0xD5, 420000 baud, failsafe "cut" | | [tbs-crsf-spec](https://github.com/tbs-fpv/tbs-crsf-spec/blob/main/crsf.md), [ExpressLRS](https://www.expresslrs.org/quick-start/receivers/wiring-up/) |
| Bộ lọc Mahony | | Mahony, Hamel, Pflimlin, IEEE TAC 2008; [ahrs docs](https://ahrs.readthedocs.io/en/latest/filters/mahony.html) |
| Mô hình động học, motor | T = Tmax·ω², trễ bậc 1 | [Gibiansky](https://andrew.gibiansky.com/blog/physics/quadcopter-dynamics/), [PX4 SITL motor model](https://github.com/PX4/sitl_gazebo/issues/110) |
| Lực cản rotor tuyến tính theo vận tốc gió | | Faessler, Franchi, Scaramuzza, RA-L 2018 |

**GIẢ ĐỊNH (chưa có khung thật):** khung ~0,6 kg, 225 mm, 6 N/motor, quán tính, lực cản,
chiều quay cánh (props-in), rung khung, độ trễ link 5 ms. Các hệ số PID được chỉnh trên mô hình
giả định này, **chỉ là điểm xuất phát, chưa phải bộ chỉnh cho drone thật**.

## Giới hạn đã biết

- Không có GPS / la bàn: không giữ vị trí (gió sẽ đẩy trôi), hướng mũi trôi theo gyro.
- Không có vận tốc từ GPS thì khi drone đang tăng tốc ngang, accelerometer không phân biệt được
  nghiêng với gia tốc: ở `angle_step` góc ước lượng lệch góc thật ~2° trong lúc tăng tốc. Hết khi có
  GPS (EKF, giai đoạn 3 của plan mục 9).
- Thời gian chạy trên Mac (`sim_cli --bench`) không nói gì về MCU: HPMCU là rv32imc **không có FPU**
  (`rtconfig.py:38`), mọi phép float là gọi hàm mềm. Phải đo trên board.

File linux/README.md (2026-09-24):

# Phía Linux

| Thư mục | Nội dung |
|---|---|
| `dts/rv1103g-luckfox-pico-mini-m1.dts` | DTS Mini gốc + `reserved-memory` cho MCU. Cài vào SDK bằng `tools/install_m1.sh` |
| `mcu-tool/` | nạp/dừng MCU, đọc log và kết quả benchmark qua `/dev/mem`. Build: `tools/build_linux_tools.sh` |
| `dts/sdk/` | bản sao DTS của SDK **chỉ để đọc**, không nằm trong git. Tạo lại: `tools/extract_sdk_ref.sh` |

## Chuỗi include của Luckfox Pico Mini

```
rv1103g-luckfox-pico-mini-m1.dts   (repo)
└── rv1103g-luckfox-pico-mini.dts
    ├── rv1103.dtsi → rv1106.dtsi
    ├── rv1106-evb.dtsi
    └── rv1103-luckfox-pico-ipc.dtsi
        └── rv1106-amp.dtsi        node rockchip,amp: giữ clock MCU bật
```

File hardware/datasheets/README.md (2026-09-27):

# Datasheet (không lưu trong repo)

Datasheet là tài liệu có bản quyền của hãng, nên không đưa vào repo. Tải về bằng:

```sh
hardware/fetch_vendor.sh      # tải PDF từ trang chính thức, tạo bản .txt bằng pdftotext
```

Các file `.txt` là bản chữ trích từ PDF. Tài liệu trong repo trích dẫn số liệu theo tên file,
phiên bản và trang.

| File | Linh kiện | Nguồn chính thức |
|---|---|---|
| `TPS54360.pdf` | buck 5 V (U1), SLVSBB4G | https://www.ti.com/lit/ds/symlink/tps54360.pdf |
| `TPS54560B.pdf` | tham khảo cho buck | https://www.ti.com/lit/ds/symlink/tps54560b.pdf |
| `LM66100.pdf` | diode lý tưởng (U2), SLVSEZ8A | https://www.ti.com/lit/ds/symlink/lm66100.pdf |
| `TLV755P.pdf` | LDO 3,3 V cảm biến (U3) | https://www.ti.com/lit/ds/symlink/tlv755p.pdf |
| `BMP390.pdf` | barometer (U5) | https://www.bosch-sensortec.com/media/boschsensortec/downloads/datasheets/bst-bmp390-ds002.pdf |
| `ICM-42688-P_DS-000347_v1.7.pdf` | IMU (U4) | **tải tay**: https://invensense.tdk.com/products/motion-tracking/6-axis/icm-42688-p/ (link PDF trực tiếp của TDK trả về trang HTML, không tải bằng script được) |
| `../vendor/Luckfox-Pico-Mini.pdf` | sơ đồ nguyên lý Luckfox Pico Mini | https://github.com/LuckfoxTECH/Luckfox-Pico-docs (Hardware/Schematic) |

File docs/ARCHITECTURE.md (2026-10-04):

# Kiến trúc: phần cứng đã xác minh và hướng đi

SDK: LuckfoxTECH/luckfox-pico `main` @ `824b817f889c2cbff1d48fcdb18ab494a68f69d1`. Đường dẫn tính từ gốc SDK.
"TEST" = đo trực tiếp trên board Luckfox Pico Mini B đang chạy firmware build từ SDK này (2026-09-23).

## SoC

| Mục | Giá trị | Nguồn |
|---|---|---|
| SoC | RV1103 (package 38x38, bản "G") | TEST: `/proc/device-tree/compatible` = `rockchip,rv1103g-38x38-ipc-v10 rockchip,rv1103` |
| DTS board | `rv1103g-luckfox-pico-mini.dts` | `project/cfg/BoardConfig_IPC/BoardConfig-SPI_NAND-Buildroot-RV1103_Luckfox_Pico_Mini-IPC.mk` (`RK_KERNEL_DTS`) |
| Họ chip | RV1106 (RV1103 dùng chung `rv1106.dtsi`, `RK_CHIP=rv1106`) | cùng file BoardConfig (`RK_CHIP=rv1106`); `rkdeveloptool rci` trả `36 30 31 31` ("1106" đảo byte) |

## Cortex-A7 (Linux)

| Mục | Giá trị | Nguồn |
|---|---|---|
| Kiến trúc | ARMv7, 1 nhân (`processor : 0`), rev 5 | TEST: `/proc/cpuinfo` |
| Clock hiện tại | 1104 MHz | TEST: `clk_summary` → `armclk 1104000000` |
| Các mức DVFS | 408 / 600 / 816 / 1104 MHz | TEST: `scaling_available_frequencies` |
| DDR | 64 MB, bắt đầu ở 0x0 | TEST: `/proc/device-tree/memory/reg` = `<0x0 0x04000000>` |
| RAM Linux dùng được | 32596 kB (MemTotal), CMA 24576 kB giữ cho camera/ISP | TEST: `/proc/meminfo` |
| GPU / framebuffer | không có | TEST: không có `/dev/dri`, `/dev/fb*`, `/dev/mali*` |
| NAND | 128 MB SPI NAND (SAMSUNG, block 128 KB, page 2 KB) | TEST: `rkdeveloptool rfi` |

## MCU phụ (HPMCU)

Bằng chứng đầy đủ: [RV1103_MCU.md](RV1103_MCU.md).

| Mục | Giá trị | Trạng thái |
|---|---|---|
| Nhân | RISC-V Syntacore SCR1, `rv32imc`, ilp32 | từ source (`rtconfig.py:38`) |
| Clock | 297 MHz | TEST (`clk_core_mcu`) + khớp `timer.h:34` |
| SRAM riêng | 8 KB (`hpmcu_sram`) | từ DTS; MCU có chạy code từ đây không: UNKNOWN |
| Vùng chạy code | DDR; SDK mặc định 0x40000 **nằm trong kernel**, repo dùng 0x01800000 (đề xuất) | [MEMORY_MAP.md](MEMORY_MAP.md) |
| Bộ điều khiển ngắt | SCR1 IPIC + INT_MUX 0xFF5D0000 | từ source |
| Timer hệ thống | SCR1 mtime @ 0xFF1E0000, bộ chia 1000 | `timer.c:135-147`; nguồn clock của mtime: UNKNOWN |
| Watchdog | không thấy trong bảng ngắt của MCU | UNKNOWN |

## Còn một MCU thứ hai?

HAL có thanh ghi `LPMCU_BOOT_ADDR` (`sysdrv/source/mcu/rt-thread/bsp/rockchip/common/hal/lib/CMSIS/Device/RV1106/Include/rv1106.h:52`)
và kernel có clock `clk_pmu_mcu` (TEST: 198 MHz, **đang tắt**). Nhiều khả năng có một MCU công suất thấp trong miền PMU.
SDK không có firmware hay luồng build nào cho nó. **Chưa xác minh**, không dùng cho tới khi có tài liệu.

## Hướng kiến trúc

Tài liệu đầy đủ có sơ đồ: [architecture.html](architecture.html) (phần cứng, phân chân, phần mềm, IPC, failsafe, bộ nhớ, rủi ro, phương án B).

Mục tiêu: một chip RV1103, Linux trên Cortex-A7 lo camera, AI, mạng; HPMCU chạy vòng điều khiển bay.
Trạng thái: **NOT YET DEMONSTRATED**. Milestone 1 PASS: MCU chạy 1 kHz cùng Linux, 0 lỡ chu kỳ trên 2 000 000 vòng,
jitter 18,2 µs khi idle và 116,7 µs khi camera chạy ([REALTIME.md](REALTIME.md)).

| Miền | Phần cứng (đề xuất) | Phần mềm (đề xuất) |
|---|---|---|
| MCU | SPI0 (chân 6–9, CS1 chân 14): IMU ICM-42688-P + barometer; PWM2 kênh 8–11 (chân 10, 11, 16, 17): 4 ESC | RT-Thread: ctrl_rate 1 kHz, ctrl_att 250 Hz, ctrl_alt 100 Hz, safety 100 Hz, comms 100 Hz, blackbox |
| Linux | CSI camera; UART3 (chân 12/13): module LTE + GNSS Lierda NT26-KCN E; chân 18 / 20: RESET / BOOT của module; SARADC IN0 (chân 19): áp pin; USB host: Wi-Fi | vision, flight-manager, telemetry + web, blackbox-writer, mcu-loader, lte-loader (nạp firmware Lierda) |
| Chung | DDR: MCU 0x01800000 (256 KB, đã chạy) + IPC 0x01840000 (256 KB, đề xuất) | vòng đệm SPSC + polling (không có mailbox driver, không có RPMsg cho RV1106) |

Những điểm có thể buộc phải dùng MCU điều khiển bay rời (phương án B):

| Vấn đề | Bằng chứng | Ảnh hưởng |
|---|---|---|
| HAL MCU không có SPI, không có UART | `hal_bsp.c` chỉ có I2C0–4, PWM0–2, UART0/2 | phải tự viết mô tả thiết bị + kiểm clock |
| Không thấy ngắt DMA trong bảng ngắt của MCU | `soc.h:53-94` | DShot bằng Timer+DMA có thể không làm được |
| Tải camera làm jitter MCU tăng 6,4 lần | [REALTIME.md](REALTIME.md) | phải đo thêm với NPU + Wi-Fi |
| Bộ thu RC (ELRS/CRSF) dùng UART2, đường RC đi qua Linux | [PERIPHERALS.md](PERIPHERALS.md#bộ-thu-rc-trên-uart2) | Linux treo = mất RC; MCU phải failsafe theo timeout. MCU tự đọc UART2 cần viết mã clock (UNKNOWN) |
| Không có RPMsg/mailbox driver cho RV1106 | [IPC.md](IPC.md) | IPC tự làm |
| Lỗi tick trong SDK | `timer.c:128`, chậm 0,1% | phải sửa trước khi chạy dài |

Quyết định giữ hay bỏ kiến trúc một chip chỉ đưa ra sau khi có số liệu của Milestone 2.

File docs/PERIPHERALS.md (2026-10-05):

# Ngoại vi: ai sở hữu, MCU có dùng được không

Viết tắt như [RV1103_MCU.md](RV1103_MCU.md). "Linux bật" = `status = "okay"` trong DTS của Luckfox Pico Mini
(`DTS/rv1103g-luckfox-pico-mini.dts` + `DTS/rv1103-luckfox-pico-ipc.dtsi`).

## Linux đang dùng (không đưa cho MCU)

| Khối | Địa chỉ | DTS bật ở | Dùng cho |
|---|---|---|---|
| UART2 | 0xFF4C0000 | bootargs `earlycon=…0xff4c0000 console=ttyFIQ0` (`rv1103-luckfox-pico-ipc.dtsi:9`) | console Linux |
| I2C4 | 0xFF470000 | `rv1103-luckfox-pico-ipc.dtsi:168` | camera |
| MIPI CSI, ISP, VICAP | 0xFFA00000… | `rv1103-luckfox-pico-ipc.dtsi:120-301` | camera |
| NPU | 0xFF660000 | `rv1106-evb.dtsi:55` | AI |
| Encoder (rkvenc) | 0xFFA50000 | `rv1106-evb.dtsi:67-71` | video |
| USB (dwc3) | 0xFFB00000 | `rv1103g-luckfox-pico-mini.dts:55` | USB OTG / mạng ECM |
| SARADC | 0xFF3C0000 | `rv1103-luckfox-pico-ipc.dtsi:92` | |
| SFC (SPI NAND) | | `rv1103g-luckfox-pico-mini.dts:18` | lưu trữ |

## Khai báo nhưng Linux tắt: ứng viên cho MCU

| Khối | Địa chỉ | Chân (pinmux) | Nguồn |
|---|---|---|---|
| SPI0_M0 | 0xFF500000 | CLK GPIO1_C1, MOSI GPIO1_C2, MISO GPIO1_C3, CS0 GPIO1_C0 | `mini.dts:60-67`; `rv1106-pinctrl.dtsi:834-848`; `rv1106.dtsi:1059` |
| UART3_M1 | 0xFF4D0000 | TX GPIO1_D0, RX GPIO1_D1 (mux 5) | `mini.dts:77-80`; `rv1106-pinctrl.dtsi:1014-1019`; `rv1106.dtsi:1014` |
| UART4_M1 | 0xFF4E0000 | RX GPIO1_C4, TX GPIO1_C5 (mux 4) | `mini.dts:82-85`; `rv1106-pinctrl.dtsi:1034-1039`; `rv1106.dtsi:1029` |
| PWM1_M0 | 0xFF350010 | GPIO0_A4 | `mini.dts:87-91`; `rv1106-pinctrl.dtsi:454-457`; `rv1106.dtsi:580` |
| I2C3_M1 | 0xFF460000 | | `mini.dts:69-74`; `rv1106.dtsi:879` |

## Chân trên header của Luckfox Pico Mini

Nguồn: ảnh sơ đồ chân của Luckfox (`Luckfox-Pico-Mini-details-inter.jpg`, người dùng cung cấp 2026-09-24),
đối chiếu với `rv1106-pinctrl.dtsi`. "Khớp" = ảnh và DTS cùng nói một chức năng cho chân đó.

| Chân | GPIO | Chức năng dùng tới | Đối chiếu DTS |
|---|---|---|---|
| 2, 21 | GND | | |
| 3 | 3V3 (ra) | | |
| 4 | GPIO1_B2 | **UART2_TX_M1: console Linux** → trên board LFX_FC_R1: RC_TX (tới RX bộ thu) | khớp: `rv1106-pinctrl.dtsi:998-999`, UART2 dùng M1 `rv1106.dtsi:1010` |
| 5 | GPIO1_B3 | **UART2_RX_M1: console Linux** → trên board LFX_FC_R1: RC_RX (từ TX bộ thu, CRSF) | khớp: `rv1106-pinctrl.dtsi:996-997` |
| 6–9 | GPIO1_C0–C3 | SPI0_M0 CS0/CLK/MOSI/MISO; hoặc PWM2/4/5/6_M2 | SPI khớp `:834-848`; PWM mux 3 `:494,540,563,586` |
| 10 | GPIO1_C4 | UART4 (M1); hoặc PWM8_M1 | PWM `:625`; **hướng UART lệch**: ảnh ghi TX, DTS ghi `uart4_rx_m1` (`:1036-1037`) |
| 11 | GPIO1_C5 | UART4 (M1); hoặc PWM9_M1 | PWM `:641`; ảnh ghi RX, DTS ghi `uart4_tx_m1` (`:1038-1039`) |
| 12 | GPIO1_D0 | UART3_TX_M1 | khớp `:1018-1019` |
| 13 | GPIO1_D1 | UART3_RX_M1 | khớp `:1016-1017` |
| 14, 15 | GPIO1_D2, D3 | I2C3_M1 SDA/SCL | |
| 18 | GPIO0_A4 | PWM1_M0 (ảnh không ghi) | `:454-457` |

Hướng TX/RX của UART4_M1: **UNKNOWN — NEED VERIFICATION** (ảnh và DTS nói ngược nhau). Đo bằng máy hiện sóng trước khi dùng.

Các chân PWM khác mà ảnh không ghi, tra từ `rv1106-pinctrl.dtsi`:
chân 12 PWM3_M2 (`:514`), 13 PWM10_M2 (`:661`), 14 PWM0_M1 (`:445`), 15 PWM11_M2 (`:684`),
16 PWM10_M1 (`:654`), 17 PWM11_M1 (`:677`), 20 PWM1_M1 (`:461`).

`spi0_cs1n_m0` là GPIO1_D2 = **chân 14** (`:852-855`); ảnh ghi CS1 ở chân 15. **Lệch giữa ảnh và DTS**, theo DTS.

**PWM cho ESC x4 (đề xuất):** PWM8/9/10/11_M1 ở chân 10, 11, 16, 17. Cả 4 kênh thuộc cùng bộ PWM @ 0xFF490000,
chính là `g_pwm2Dev` trong HAL MCU (`hal_bsp.c:99-105`, `rv1106.h:790`). Không trùng chân SPI0 (6–9).

## Điều kiện để MCU dùng một khối

1. **Linux không bind driver**: giữ `status = "disabled"`.
2. **Clock không bị Linux tắt**: kernel tắt mọi clock không ai dùng lúc khởi động xong (`clk_disable_unused`).
   Phải thêm clock của khối đó vào node `rockchip,amp` (`DTS/rv1106-amp.dtsi`). Driver `rockchip_amp.c` bật và giữ mọi clock trong danh sách.
3. **MCU có ngắt**: có trong bảng `HAL_MCU_CORE` (`soc.h:53-94`).
4. **HAL có mô tả thiết bị + mã clock cho RV1106**: UART thì **không** (`hal_bsp.c:120` chỉ có UART2; không có `CLK_UART*` nào cho RV1106).
   PWM0–2 và I2C0–4 **có** (`hal_bsp.c:28-107`). **SPI không có** mô tả thiết bị. DMA: **UNKNOWN**.

## UART debug cho MCU

Không có đường chính thức (điều kiện 4). Milestone 1 dùng vòng đệm log trong RAM (`drv_pstore.c`), đọc bằng `mcu-tool log`.
Muốn UART thật cho MCU thì phải tự viết driver polled cho UART3 (DW 8250) và kiểm clock `SCLK_UART3` trên board. Đây là việc riêng, chưa làm.

## Bộ thu RC trên UART2

Board LFX_FC_R1 dùng UART2 (chân 4/5), UART cuối cùng còn trống, cho bộ thu ExpressLRS / Crossfire. Cổng J4, JST-SH 4 chân: 1 = 5 V, 2 = GND, 3 = TX của board (tới RX bộ thu), 4 = RX của board (từ TX bộ thu).

| Mục | Giá trị | Nguồn |
|---|---|---|
| Giao thức | CRSF: một cặp UART đầy đủ, không đảo, full-duplex | [expresslrs.org: Receiver Wiring](https://www.expresslrs.org/quick-start/receivers/wiring-up/), [Configuring FC](https://www.expresslrs.org/quick-start/receivers/configuring-fc/) |
| Baud | 420000 (mặc định của ELRS); chuẩn TBS là 416666 | [betaflight#12398](https://github.com/betaflight/betaflight/issues/12398) |
| Nguồn bộ thu | 5 V | expresslrs.org, Receiver Wiring |
| Clock UART2 | có bộ chia phân số riêng `clk_uart2_frac` | `drivers/clk/rockchip/clk-rv1106.c:441` |
| Tạo 420000 baud | 16 × 420000 = 6,72 MHz = 24 MHz × 7/25: về lý thuyết chia đúng | tính toán; **chưa đo, UNKNOWN — NEED VERIFICATION** |
| Console hiện tại | `earlycon=uart8250,mmio32,0xff4c0000`, `fiq-debugger` `rockchip,serial-id = <2>` | `rv1106.dtsi:225-232`, `rv1106-ipc.dtsi:9` |
| Pull-up RC_RX | R24 1 kΩ lên 3,3 V của module (chân 3): bộ thu dùng ESP bị kẹt ở bootloader nếu đường này bị kéo thấp khi cấp nguồn | expresslrs.org, Receiver Wiring (300–1000 Ω) |

Việc phần mềm phải làm trước khi cắm bộ thu (chưa làm):

1. Bỏ console khỏi UART2: tắt `fiq-debugger`, bỏ `earlycon`/`console=ttyFIQ0` trong bootargs, bật node `uart2` cho Linux. U-Boot và DDR blob vẫn in log lúc boot ra UART2; bộ thu sẽ nhận rác ở 115200/1500000 nhưng gói CRSF có CRC nên bỏ qua. Có tắt được log DDR blob không: UNKNOWN.
2. Debug: dùng ADB qua USB, hoặc gắn USB-UART vào TP5/TP6 khi đã rút bộ thu.
3. Đường RC: bộ thu → Linux (UART2) → IPC → MCU. Linux treo là mất RC, nên MCU phải tự failsafe khi mất heartbeat. MCU tự đọc UART2 thì phải viết mã clock UART cho RV1106 (HAL không có, xem mục 4 ở trên).

## LFX_FC_R2: GPS ngoài trên UART5 (2026-10-04)

R2 hết chân trống: UART2 cho bộ thu RC, UART3 cho modem Lierda. Để gắn module GPS rời (ATGM336H) mà vẫn giữ cả hai, chân 14 và 15 được đổi vai:

| Chân | GPIO | Trước | Sau | Nguồn |
|---|---|---|---|---|
| 14 | GPIO1_D2 | SPI0_CS1 → barometer | **UART5_RX_M1** ← GPS (J18) | `rv1106-pinctrl.dtsi:1082-1083` (`uart5_rx_m1`, mux 4, `pcfg_pull_up`) |
| 15 | GPIO1_D3 | ngắt IMU (dự phòng) | **CS của barometer**, GPIO do MCU điều khiển | UART5_TX_M1 cũng là chân này (`:1084-1085`), nên không dùng được: GPS chỉ gửi |

Việc phần mềm phải làm (chưa làm):
1. **DTS:** bật `uart5` với nhóm pinctrl **chỉ có RX** (`<1 RK_PD2 4 &pcfg_pull_up>`), vì `uart5m1_xfer` mặc định chiếm cả D3. Linux đọc NMEA ở `/dev/ttyS5` (tên thật: UNKNOWN), 9600 baud.
2. **MCU:** đọc BMP390 bằng CS dạng GPIO (GPIO1_D3) thay cho CS1 phần cứng của SPI0.
3. **Bank GPIO1 dùng chung:** Linux cũng giữ các chân khác của bank GPIO1. Ghi chân CS từ MCU phải dùng thanh ghi có write-mask của Rockchip (`GPIO_SWPORT_DR_L/H`, 16 bit cao là bit cho phép ghi), để không giẫm lên Linux. Có đúng như vậy trên RV1106 không: **UNKNOWN — NEED VERIFICATION** trên TRM.

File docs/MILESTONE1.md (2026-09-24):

# Milestone 1: Linux + RT-Thread trên HPMCU + vòng lặp 1 kHz

## Trạng thái (2026-09-24)

| Tiêu chí | Trạng thái | Bằng chứng |
|---|---|---|
| Stock SDK build | **PASS** | `logs/sdk_build.log`; ảnh trong `images/` (build 2026-09-23) |
| Linux boot | **PASS** (firmware stock) | TEST 2026-09-23: SSH, `/proc/cpuinfo`, `clk_summary` |
| RT-Thread firmware build | **PASS** | `tools/build_mcu.sh luckfox_mini-M1-NONE` → 22 072 B, entry 0x1800200 |
| Linux M1 (DTS có reserved-memory) build + flash | **PASS** | `images/boot.img` có `mcu@1800000`; `/proc/iomem` loại vùng MCU |
| MCU firmware boot | **PASS** (nạp từ Linux bằng `mcu-tool`) | `logs/m1_load.txt`, `logs/m1_first_log.txt` |
| UART debug | **Linux: PASS** (UART2 qua J-Link VCOM, 115200). **MCU: không có UART** trong SDK cho RV1106, dùng log trong RAM (`mcu-tool log`) | `logs/m1_uart_boot1.txt` |
| Vòng lặp 1 kHz chạy | **PASS**: 1 000 000 vòng, 0 missed, 0 overrun | `logs/m1_run1_rkipc.txt` |
| Đo jitter | **PASS**: Linux idle jitter max 18,2 µs; dưới tải `rkipc` 116,7 µs | [REALTIME.md](REALTIME.md) |

Milestone 1: **PASS, có một điểm lệch**: debug MCU qua log trong RAM thay vì UART (SDK không hỗ trợ UART cho MCU RV1106).

## Cần có

- Board Luckfox Pico Mini B, cáp USB-C truyền dữ liệu.
- (Nên có) USB-UART **3,3 V** để xem console U-Boot và Linux trên UART2, **115200 8N1** (`rv1106.dtsi:227,230`):

  | USB-UART | Chân board |
  |---|---|
  | RX | 4 (GPIO1_B2, UART2_TX_M1) |
  | TX | 5 (GPIO1_B3, UART2_RX_M1) |
  | GND | 2 hoặc 21 |
  | VCC | **không nối**, board cấp nguồn qua USB-C |

  Trên Mac: `screen /dev/cu.usbserial-* 115200` (thoát: Ctrl-A rồi K). Nguồn chân: [PERIPHERALS.md](PERIPHERALS.md).

## 1. Build (trên Mac)

```sh
orb start                                   # nếu Docker engine đang tắt
tools/build_mcu.sh luckfox_mini-M1-NONE     # → out/mcu/luckfox_mini-M1-NONE/rtthread.bin
tools/build_linux_tools.sh                  # → out/linux-tools/mcu-tool
tools/install_m1.sh                         # đưa DTS + BoardConfig M1 vào SDK
./run.sh board                              # chọn dòng ...Mini_M1-IPC
./run.sh build                              # build lại U-Boot + kernel + firmware, ảnh ra images/
```

`./run.sh build` xóa ảnh cũ trong `images/` rồi chép ảnh mới vào (đầu ra của repo nằm ở `out/`, không bị xóa).
Quay lại firmware stock: `./run.sh board` chọn lại `...Mini-IPC`, rồi `./run.sh build`.

## 2. Nạp firmware Linux

```sh
./run.sh flash       # vào chế độ nạp qua ADB, ghi mọi phân vùng; xóa dữ liệu trên board
./run.sh connect     # chờ board lên, gắn IP USB-ECM, mở SSH root@172.32.0.93
```

## 3. Kiểm tra vùng nhớ trước khi chạy MCU (bắt buộc)

```sh
B=root@172.32.0.93
ssh $B 'hexdump -C /proc/device-tree/reserved-memory/mcu@1800000/reg'   # phải là 01 80 00 00 00 04 00 00
ssh $B 'cat /proc/iomem'                                                # 0x01800000-0x0183ffff không thuộc System RAM
```
Trên console UART2, dừng U-Boot bằng phím bất kỳ rồi `bdinfo`: `relocaddr` phải > 0x01840000.
Sai bất kỳ điều nào thì **dừng**, không nạp MCU.

## 4. Nạp và chạy MCU (từ Linux)

```sh
cat out/mcu/luckfox_mini-M1-NONE/rtthread.bin | ssh $B 'cat > /tmp/rtthread.bin'
cat out/linux-tools/mcu-tool                 | ssh $B 'cat > /tmp/mcu-tool && chmod +x /tmp/mcu-tool'
ssh $B '/tmp/mcu-tool load /tmp/rtthread.bin'
ssh $B 'sleep 3; /tmp/mcu-tool log'          # phải thấy "bench: clock ..." và "Hello RV1103 MCU 0, 1, 2"
ssh $B '/tmp/mcu-tool status'
ssh $B '/tmp/mcu-tool clock 30'              # tần số bộ đếm MCU đo theo đồng hồ Linux
ssh $B '/tmp/mcu-tool stop'                  # giữ MCU ở reset
```

`mcu-tool load` sẽ từ chối nếu:
- device tree không có `reserved-memory/mcu@1800000` đúng địa chỉ và kích thước;
- đọc lại firmware trong DDR không khớp;
- Linux không ghi được `HPMCU_BOOT_ADDR` (thanh ghi secure). Khi đó MCU vẫn giữ reset, và phải chuyển sang đường nạp bằng SPL FIT ([RV1103_MCU.md §2](RV1103_MCU.md)).

## 5. Đo và lưu kết quả

Mỗi lần chạy 1 000 000 vòng mất khoảng 16,7 phút:
```sh
sleep 1080; ssh $B '/tmp/mcu-tool status; /tmp/mcu-tool clock 30' | tee logs/m1_idle.txt
```
Các kịch bản tải: [REALTIME.md](REALTIME.md).

## 6. Nếu không thấy log

| Triệu chứng | Nghĩa là |
|---|---|
| `vong dem log chua khoi tao` | MCU không chạy tới `pstore_dev_init`: không boot, sai địa chỉ, hoặc cache chưa được đẩy ra DDR |
| Log dừng ở `bench: probing mcycle` | đọc CSR `mcycle` gây lỗi trên lõi này; sửa `clock_select()` để chỉ dùng mtime |
| `heartbeat` không tăng | MCU treo hoặc tick không chạy |
| Linux treo hoặc panic sau `load` | vùng nhớ không thực sự trống: dừng, kiểm tra lại mục 3 |

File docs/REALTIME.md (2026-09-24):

# Benchmark vòng lặp 1 kHz trên MCU

Code: `mcu/bsp/luckfox_mini-M1-NONE/rt_bench.c`. Chưa được gọi hệ thống là hard-real-time.

## Kết quả

| Kịch bản | Log | n | missed | overrun | period min / avg / max (µs) | jitter max | P50 / P95 / P99 / P99.9 / P99.99 (µs) | latency avg / P99 / P99.99 / max (µs) |
|---|---|---|---|---|---|---|---|---|
| Firmware mặc định: `rkipc` chạy (camera + ISP + encoder), load 11,3 | `logs/m1_run1_rkipc.txt` | 1 000 000 | 0 | 0 | 894,7 / 1000,999 / 1116,7 | 116,7 µs | 1001,25 / 1010,0 / 1021,25 / 1053,0 / 1099,75 | 9,1 / 21,6 / 63,7 / 107,1 |
| Linux idle: `RkLunch-stop.sh`, không còn `rkipc`, CPU idle 83% (load ≈ 10 do các luồng media kernel ở trạng thái D) | `logs/m1_run2_idle.txt` | 1 000 000 | 0 | 0 | 984,9 / 1000,999 / 1018,2 | 18,2 µs | 1001,0 / 1001,5 / 1001,75 / 1008,0 / 1013,0 | 6,8 / 7,3 / 13,0 / 15,1 |

- Chu kỳ trung bình 1,000999 ms thay vì 1 ms: tick RT-Thread của SDK chậm 0,1% (xem [RV1103_MCU.md §4](RV1103_MCU.md)).
- Percentile là cận trên của ô histogram (250 ns cho period, 100 ns cho latency).
- Lần chạy dưới tải `rkipc` có 9 mẫu latency vượt 100 µs (`hist overflow`).
- **Tải media trên Linux làm jitter của MCU tăng khoảng 6,4 lần** (18,2 → 116,7 µs), dù MCU có lõi riêng.
  Giả thuyết: code và dữ liệu MCU nằm trong DDR, tranh băng thông với ISP/encoder khi cache miss. **Chưa chứng minh nguyên nhân.**
  Có thể thử: chạy vòng lặp từ `hpmcu_sram` (8 KB), kiểm tra D-cache MCU có bật không.

## Cách đo

```
tick mtime (1 ms) ──ISR──► hard timer RT-Thread ──► ghi t_isr, rt_sem_release
                                                     │
thread "bench" (ưu tiên 1, cao nhất của ứng dụng) ◄──┘ rt_sem_take → ghi t_wake
```

| Đại lượng | Định nghĩa |
|---|---|
| period | `t_wake[i] − t_wake[i−1]`, mục tiêu 1 000 000 ns |
| jitter | `max |period − 1 ms|` |
| latency | `t_wake − t_isr` (từ callback trong ngắt tới lúc thread chạy) |
| missed | period > 1,5 ms |
| overrun | khi thread thức dậy semaphore vẫn còn token, tức là đã có thêm tick trong lúc thread chưa chạy |
| P50…P99.99 | từ histogram: period ô 250 ns trong 0–2,5 ms; latency ô 100 ns trong 0–100 µs. Giá trị báo cáo là **cận trên của ô**. Mẫu vượt khoảng tính vào `hist_overflow` |

- Nguồn thời gian: `mcycle` (≈ 3,37 ns) nếu bộ đếm này chạy, không thì `mtime` (≈ 3,37 µs, kết quả thô). `mcu-tool status` in rõ đang dùng nguồn nào.
- Tần số danh nghĩa 297 MHz lấy từ `timer.h:34`. `mcu-tool clock` đo lại tần số bộ đếm theo `CLOCK_MONOTONIC` của Linux.
- Mỗi lần chạy = 1 000 000 vòng (≈ 16,7 phút), xong thì chạy tiếp. Mỗi lần chạy xong in kết quả vào log và `last`.
- Trong lúc chạy, thread báo cáo tắt ngắt khoảng vài chục chu kỳ để chép số liệu. Việc này nằm trong kết quả đo.

## Những gì có thể làm sai kết quả

| Rủi ro | Nguồn | Xử lý |
|---|---|---|
| Nhịp đo chính là tick mtime: sai số tần số tick không lộ ra ở period nếu đo bằng cùng clock | thiết kế | `mcu-tool clock` so với đồng hồ Linux |
| Lỗi `timer.c:128`: sau ≈ 4 h tick có thể hỏng | [RV1103_MCU.md §4](RV1103_MCU.md) | chạy ≥ 6 h và theo dõi `heartbeat` |
| `drv_gpio.c` unmask ngắt GPIO trên MCU, ta mask lại ở `INIT_DEVICE_EXPORT` | `board.c` | có một khoảng hở ngắn lúc boot |
| MCU không có UART, `rt_kprintf` chỉ ghi RAM | [PERIPHERALS.md](PERIPHERALS.md) | log không ảnh hưởng timing qua UART |

## Kịch bản tải (mục 28 của kế hoạch, sau khi boot được)

1. Linux idle
2. + camera/ISP (`rkipc` mặc định của Luckfox)
3. + NPU
4. + encode video
5. + lưu lượng mạng (USB-ECM, `iperf3` nếu có)

Mỗi kịch bản ≥ 1 lần chạy đủ 1 000 000 vòng. Ghi `mcu-tool status` + `mcu-tool clock` vào `logs/`.

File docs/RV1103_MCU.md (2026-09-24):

# HPMCU của RV1103: bằng chứng (Phase 0 + Phase 2)

SDK: LuckfoxTECH/luckfox-pico `main` @ `824b817f889c2cbff1d48fcdb18ab494a68f69d1` (xem `SDK_VERSION`).
Đường dẫn tính từ gốc SDK. Viết tắt:
`MCU/` = `sysdrv/source/mcu/rt-thread/`, `BSP/` = `MCU/bsp/rockchip/rv1106-mcu/`, `HAL/` = `MCU/bsp/rockchip/common/hal/lib/`,
`UB/` = `sysdrv/source/uboot/u-boot/`, `K/` = `sysdrv/source/kernel/`, `DTS/` = `K/arch/arm/boot/dts/`.
**TEST** = đo trên board Luckfox Pico Mini B chạy firmware stock (2026-09-23).

## 1. Câu hỏi Phase 0

| Câu hỏi | Kết luận | Nguồn (file:dòng) | Giải thích |
|---|---|---|---|
| Nhân MCU | RISC-V 32-bit, `rv32imc`, ABI `ilp32`, lõi Syntacore SCR1 | `BSP/rtconfig.py:38`; thư mục `MCU/libcpu/risc-v/scr1/`; ELF đã build: "RISC-V, RVC, soft-float" | cờ biên dịch và port CPU mà BSP dùng |
| Clock MCU | 297 MHz | `BSP/drivers/timer.h:34`; TEST `clk_core_mcu` = 297 MHz | kernel khai báo `clk_core_mcu` từ gpll/24M, không critical (`K/drivers/clk/rockchip/clk-rv1106.c:335-337`) |
| SRAM riêng | 8 KB `hpmcu_sram` @ 0xFF6FE000 | `DTS/rv1106.dtsi:1140,1149` | nằm trong system_sram 0xFF6C0000; MCU có chạy code từ đây không: **UNKNOWN — NEED VERIFICATION** |
| RAM chạy code | DDR, SDK mặc định 0x40000, dài 0x3C000 | `BSP/link.lds:5` | firmware chạy trong DDR chung với Linux |
| RT-Thread | 3.1.3 | defconfig `CONFIG_RT_VER_NUM=0x30103` | |
| Toolchain | xPack `riscv-none-embed-gcc` 10.2.0 | `sysdrv/source/mcu/prebuilts/gcc/linux-x86/riscv64/`; tải bởi `project/build.sh:883-894` | |
| Lệnh build | `./build.sh mcu <Board-Sensor-Light>` | `project/build.sh:876-919, 2764-2765` | tên board phải có đúng 3 phần ngăn bởi `-`, nếu không `mcu/build.sh lunch` báo "Not found" |
| Firmware ra ở đâu | `output/out/mcu_out/rtthread.bin` | `project/build.sh:57,70` | |
| MCU boot thế nào | SPL nạp ảnh FIT "standalone" tên `mcu0`, rồi: đặt vùng ngoại vi không cache, reset MCU, ghi `HPMCU_BOOT_ADDR`, nhả reset | `UB/common/spl/spl_fit.c:655-676` → `UB/arch/arm/mach-rockchip/rv1106/rv1106.c:548-566` | xem mục 2 |
| Linux và MCU chạy đồng thời? | **Có (TEST 2026-09-24)**. Node `rockchip,amp` giữ clock MCU bật (clk_summary: `clk_core_mcu` 297 MHz, enable 1) | `DTS/rv1106-amp.dtsi`; `K/drivers/soc/rockchip/rockchip_amp.c`; `logs/m1_first_log.txt` | Linux vẫn chạy `rkipc`, SSH/ADB bình thường khi MCU chạy |

## 2. Đường khởi động MCU

| Bước | Bằng chứng |
|---|---|
| SPL của U-Boot trên Luckfox được build với `CONFIG_SPL_LOAD_FIT=y` | `UB/configs/luckfox_rv1106_uboot_defconfig:26` |
| Loader non-TB mà Luckfox dùng lấy SPL **build sẵn** `rv1106_spl_v1.02.bin`, không build từ source | `sysdrv/source/uboot/rkbin/RKBOOT/RV1106MINIALL.ini` (`FlashBoot=bin/rv11/rv1106_spl_v1.02.bin`) |
| SPL build sẵn đó có mã nhả MCU | `strings rkbin/bin/rv11/rv1106_spl_v1.02.bin` có `mcu0`, `mcu1`, `standalone`, `%s: start standalone fail, ret=%d` (chuỗi của `spl_fit.c:675`) |
| Đóng gói MCU vào FIT: `fit_args.sh -m0 <offset>` + file `mcu0.bin` | `UB/arch/arm/mach-rockchip/fit_args.sh:24,132`; `fit_nodes.sh:210-265` |
| `make.sh --mcu` chép thành `mcu.bin`, trong khi `fit_nodes.sh` đọc `mcu0.bin` | `UB/make.sh:215-216` | tên không khớp: đường `--mcu` **UNKNOWN — NEED VERIFICATION** |
| Đường chính thức của SDK: loader thunder-boot có mục `Hpmcu=` | `project/build.sh:697-723`; `rkbin/RKBOOT/RV1106MINIALL_SPI_NAND_TB.ini:20,22` | Luckfox Mini không dùng TB |

Repo này nạp MCU **từ Linux** bằng `linux/mcu-tool`, làm đúng 5 lệnh ghi của `rv1106.c:552-559` qua `/dev/mem`.
**TEST 2026-09-24: chạy được.** Linux ghi được `CORE_SGRF_HPMCU_BOOT_ADDR` (đọc lại 0x01800000), MCU boot và in log
(`logs/m1_load.txt`, `logs/m1_first_log.txt`). Nạp lại nhiều lần (`stop` rồi `load`) cũng chạy.

## 3. Thanh ghi điều khiển MCU

| Thanh ghi | Địa chỉ | Nguồn |
|---|---|---|
| `CORE_GRF_BASE` | 0xFF040000 | `UB/.../rv1106.c:23` |
| `CACHE_PERI_ADDR_START/END` | +0x24 / +0x28, giá trị 0xFF000 / 0xFFC00 | `rv1106.c:24-25,552-553`; HAL `rv1106.h:1180-1182` (trường 20 bit) |
| `CORE_SGRF_BASE` + `HPMCU_BOOT_ADDR` | 0xFF076000 + 0x44 | `rv1106.c:39,46` |
| `CORECRU_BASE` + `CORESOFTRST_CON01` | 0xFF3B8000 + 0xA04; giữ reset 0x001E001E, nhả 0x001E0000 | `rv1106.c:109-110,555,559`; HAL `rv1106.h:781` |
| SCR1 mtime | 0xFF1E0000 | `BSP/drivers/timer.h:19-25` |

## 4. Timer và đo thời gian

| Kết luận | Nguồn |
|---|---|
| Tick RT-Thread = mtime với bộ chia 1000, bước 297000/1000 = 297 đếm = 1 ms | `BSP/board/common/board_base.c:117`; `timer.c:135-147`; `timer.h:34-35` |
| Độ phân giải mtime ≈ 3,37 µs, quá thô để đo jitter | suy ra từ trên; ngữ nghĩa bộ chia (chia N hay N+1): **UNKNOWN** |
| **TEST: tick RT-Thread dài 1,000999 ms, chậm 0,1%**. `mcycle` đo theo đồng hồ Linux = 297 000 180 Hz (lệch < sai số đo, `logs/m1_clock.txt`), nên sai lệch nằm ở bộ chia mtime: phần cứng chia cho DIV+1 = 1001, SDK tính theo 1000 | `board_base.c:117`, `timer.c:140` |
| **Lỗi trong SDK**: `timer_cmp.time_cmph + 1;` không có tác dụng, nửa trên thanh so sánh không bao giờ tăng | `BSP/drivers/timer.c:128` | khi 32 bit thấp của mtime tràn (≈ 2³²/297 kHz ≈ 4,0 h) tick có thể hỏng. **Phải kiểm tra trong bài test 6 h/24 h** |
| CSR `mcycle` chạy, 297 MHz | `BSP/cpu/riscv_csr_encoding.h:863,1371`; **TEST** `mcu-tool status` báo nguồn `mcycle`, `mcu-tool clock` đo 297 000 180 Hz | |

## 5. Ngoại vi MCU nhìn thấy

Bảng ngắt riêng của MCU nằm trong `#ifdef HAL_MCU_CORE` (`HAL/CMSIS/Device/RV1106/Include/soc.h:53`).
Chi tiết từng khối: [PERIPHERALS.md](PERIPHERALS.md).

| Khối | Có ngắt phía MCU | Driver RT-Thread có trong SDK | Dùng được trên Luckfox? |
|---|---|---|---|
| Mailbox | có (`soc.h:58-59`) | `hal_mbox.c` | chưa thử |
| SPI0/1 | có (`soc.h:75-76`) | `drv_spi.c` | UNKNOWN — cần thử |
| UART0–5 | có (`soc.h:77-82`) | `drv_uart.c`, nhưng HAL RV1106 chỉ có `g_uart2Dev` (`HAL/bsp/RV1106/hal_bsp.c:120`), **không có mã clock UART nào cho RV1106** | **không, nếu không tự viết mô tả thiết bị + clock** |
| PWM0–2 | có (`soc.h:83-88`) | `drv_pwm.c` | UNKNOWN — Milestone 4 |
| TIMER0–5 | có (`soc.h:89-94`) | `hal_timer.c` | UNKNOWN |
| DMA | **không thấy trong bảng ngắt MCU** | `drv_dwdma.c`, `hal_pl330.c` | UNKNOWN — NEED VERIFICATION |
| Watchdog | không thấy trong bảng ngắt MCU | `drv_wdt.c` | UNKNOWN |

## 6. Firmware của repo

| Board | Mục đích | Vị trí link | Kích thước |
|---|---|---|---|
| `mcu/bsp/luckfox_mini-HELLO-NONE` | hello world, bố cục mặc định SDK | 0x40000 (**xung đột kernel, không chạy được song song**) | 18 256 B |
| `mcu/bsp/luckfox_mini-M1-NONE` | Milestone 1: hello mỗi giây + vòng lặp 1 kHz | 0x01800000 (đề xuất, [MEMORY_MAP.md](MEMORY_MAP.md)) | 22 072 B, heap trống ≈ 124 KB |

Build lại board mẫu của Rockchip `rv1106_evb-SC3338-ADC` cho 114 516 B, **cùng kích thước nhưng khác 60 184 byte**
so với bản build sẵn trong SDK. Chưa rõ nguyên nhân, không coi là build tái lập từng byte.

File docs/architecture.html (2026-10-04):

Luckfox Pico Mini B · RV1103 · nhánh rv1103-ai-drone

# Kiến trúc phần cứng và phần mềm cho AI quadcopter trên RV1103

Báo cáo sau Milestone 1 (2026-09-24). Kiến trúc chính là một chip: Linux trên Cortex-A7 lo camera, AI và mạng; HPMCU chạy RT-Thread lo vòng điều khiển bay. Mỗi mục có nhãn: ĐÃ KIỂM CHỨNG là đã thấy trong source hoặc đo trên board, ĐỀ XUẤT là thiết kế chưa thử, UNKNOWN là chưa có bằng chứng.

## Kết quả đã đo trên board

0 / 2 000 000chu kỳ bị lỡ trong 2 lần chạy 1 kHz, mỗi lần 1 000 000 vòng

18,2 µsjitter max khi Linux idle

116,7 µsjitter max khi camera + ISP + encoder chạy, gấp khoảng 6,4 lần

297,000 MHzclock MCU, đo bằng mcycle theo đồng hồ Linux

Kiến trúc một chip: chưa đủ bằng chứng (NOT YET DEMONSTRATED). MCU chạy ổn định song song với Linux, nhưng tải media làm jitter tăng rõ, và SPI của MCU chưa có driver. Hai điều này quyết định ở Milestone 2.

## 1. Phần cứng

do Linux quản lý do MCU quản lý module ngoài nguồn pin

Nguồn motor đi thẳng từ pin sang ESC; board chỉ nhận 5 V. Mọi đường điều khiển motor (SPI đọc IMU, PWM ra ESC) nằm trong miền MCU, nên Linux treo không kéo theo vòng điều khiển. UART2 nối bộ thu RC (ELRS/CRSF) trên board LFX_FC_R1; debug qua ADB.

### Phân chân header

Chân | GPIO | Dùng cho | Chủ | Bằng chứng | Trạng thái
1 | VBUS | 5 V từ BEC | | ảnh sơ đồ chân Luckfox | UNKNOWN cấp nguồn ngược qua chân 1 có an toàn không
2, 21 | GND | đất chung | | ảnh sơ đồ chân | ĐÃ KIỂM CHỨNG
4, 5 | GPIO1_B2/B3 | UART2: bộ thu RC CRSF (console debug khi chưa cắm bộ thu) | Linux | rv1106.dtsi:1010, pinctrl:994-999; đọc được trên board | ĐÃ KIỂM CHỨNG
6 | GPIO1_C0 | SPI0 CS0 → IMU | MCU | pinctrl:845-848 | ĐỀ XUẤT
7, 8, 9 | GPIO1_C1/C2/C3 | SPI0 CLK / MOSI / MISO | MCU | pinctrl:834-841 | ĐỀ XUẤT
14 | GPIO1_D2 | SPI0 CS1 → barometer | MCU | pinctrl:852-855 (spi0_cs1n_m0 = GPIO1_D2). Ảnh ghi CS1 ở chân 15, lệch với DTS | ĐỀ XUẤT đo lại
10, 11, 16, 17 | GPIO1_C4/C5/C6/C7 | PWM8/9/10/11_M1 → ESC 1–4 | MCU | pinctrl:625,641,654,677; HAL MCU g_pwm2Dev @ 0xFF490000 (hal_bsp.c:99-105) | ĐỀ XUẤT
12, 13 | GPIO1_D0/D1 | UART3 → module LTE + GNSS Lierda NT26-KCN E (qua SN74LVC1T45 3,3 ↔ 1,8 V): AT, GNSS, nạp firmware | Linux | pinctrl:1014-1019; đang disabled trong DTS Mini | ĐỀ XUẤT
15 | GPIO1_D3 | dự phòng: ngắt data-ready của IMU | MCU | ngắt GPIO chia theo bank, Linux cũng giữ bank GPIO1 | UNKNOWN nên bắt đầu bằng polling
18 | GPIO0_A4 | RESET_N của module LTE (mức cao = reset, qua MOSFET). Còi chuyển sang AGPIO5 của module | Linux | pinctrl:454-457 | ĐỀ XUẤT
19 | GPIO4_C0 | SARADC IN0 điện áp pin | Linux | SARADC okay trong DTS (ipc.dtsi:92) | ĐỀ XUẤT
20 | GPIO4_C1 | USB_BOOT của module LTE (bank 1,8 V, cùng mức với module): mức cao lúc reset = chế độ nạp. Không còn đo dòng ESC (dùng 4 ESC rời) | Linux | sơ đồ Luckfox: bank "SARADC/PWM (1.8V only)" | ĐỀ XUẤT
USB-C | | dev: ADB/SSH. Bay: host cho Wi-Fi | Linux | DTS Mini dr_mode = "peripheral" | UNKNOWN chuyển sang host

Hệ quả: UART4 và I2C3 không dùng được vì chân đã dành cho PWM và SPI. UART cuối cùng còn lại (UART2, vốn là console) được dành cho bộ thu RC ELRS/CRSF; console chuyển sang ADB. Đường RC đi qua Linux, xem phần rủi ro.

## 2. Phần mềm

Hai miền chỉ nói chuyện qua RAM chung, bằng polling, vì kernel không có driver mailbox cho RV1106 (rockchip-mailbox.c:163 chỉ khớp rk3368) và không có RPMsg (rockchip_rpmsg.c:402-404). MCU đọc setpoint mỗi vòng 1 ms; Linux đọc telemetry 100 Hz. Vùng IPC 256 KB nằm ở 0x01840000 ĐỀ XUẤT: phải mở rộng reserved-memory lên 512 KB.

### Gói tin IPC ĐỀ XUẤT

- Linux → MCU: timestamp, seq, mode, roll/pitch/yaw target, throttle, velocity/position target, CRC32
- MCU → Linux: timestamp, seq, attitude, gyro, accel, altitude, pin, flight_state, failsafe_flags, CRC32
- Vòng đệm SPSC, mỗi phía chỉ ghi chỉ số của mình; đọc bằng seq như mcu_bench_shared hiện tại
- Ngưỡng timeout heartbeat: UNKNOWN, chốt sau khi đo độ trễ IPC

### Ngân sách tài nguyên

- MCU: 240 KB cho code + dữ liệu; bản Milestone 1 dùng 22 KB code, 88 KB histogram, heap trống ≈ 124 KB
- Chu kỳ 1 ms; jitter đo được 18 µs (idle) đến 117 µs (camera chạy)
- Linux: MemAvailable chỉ ≈ 4,8 MB khi rkipc chạy. Phải thay rkipc bằng app camera riêng, gọn hơn
- Thời gian tính toán của vòng điều khiển: UNKNOWN, đo ở Milestone 2

## 3. Trạng thái bay và failsafe

Máy trạng thái chạy trên MCU, nên MCU tự vào failsafe khi Linux treo. Sau khi boot luôn ở DISARMED, không bao giờ tự arm. Cách hạ cánh khi không còn Linux (chỉ còn IMU và barometer) cần thiết kế riêng.

## 4. Bộ nhớ DDR

Vùng | Địa chỉ | Dùng cho | Trạng thái
Kernel code + data | 0x00008000 – 0x0078C363 | Linux | ĐÃ KIỂM CHỨNG /proc/iomem; chứa vùng 0x40000 mặc định của SDK
MCU code + data + heap | 0x01800000 – 0x0183BFFF | rtthread.bin | ĐÃ KIỂM CHỨNG đang chạy
MCU log | 0x0183C000 – 0x0183EFFF | drv_pstore | ĐÃ KIỂM CHỨNG
Benchmark | 0x0183F000 – 0x0183FFFF | mcu_bench_shared | ĐÃ KIỂM CHỨNG
IPC + blackbox | 0x01840000 – 0x0187FFFF | setpoint, telemetry, blackbox | ĐỀ XUẤT đang là RAM Linux, phải chừa thêm
U-Boot sau relocate | ≈ 0x02DF9F58 – 0x03FFFFFF | chỉ lúc boot | ĐÃ KIỂM CHỨNG log UART

## 5. Rủi ro và điều kiện chọn kiến trúc

Rủi ro | Bằng chứng | Cách kiểm tra / giảm
Camera trên Linux làm jitter MCU tăng 6,4 lần | 18,2 → 116,7 µs | chạy vòng lặp từ hpmcu_sram 8 KB; kiểm tra D-cache MCU; đo khi có NPU và Wi-Fi
HAL MCU không có mô tả thiết bị SPI | hal_bsp.c chỉ có I2C0–4, PWM0–2, UART0/2 | tự viết g_spi0Dev + kiểm clock SPI0; loopback 1/5/10 MHz
Không có DMA trong bảng ngắt MCU | soc.h:53-94 | DShot bằng PWM không DMA; có thể chỉ làm được PWM/Oneshot
RC (ELRS trên UART2) đi qua Linux, chưa có kill switch phần cứng | MCU không có mã clock UART | MCU failsafe khi mất heartbeat từ Linux; công tắc cắt nguồn ESC bằng tay; sau này cho MCU đọc UART2 trực tiếp
USB-C phải chuyển sang host để dùng Wi-Fi | dr_mode = "peripheral" | thử host + nguồn qua chân 1; mất ADB khi bay
RAM Linux rất ít | MemAvailable ≈ 4,8 MB với rkipc | app camera riêng, model NPU nhỏ
Lỗi tick trong SDK | chậm 0,1%; timer.c:128 có thể hỏng sau ≈ 4 h | sửa trong BSP của repo, test 6 h/24 h

Chuyển sang B nếu Milestone 2 cho thấy: MCU không điều khiển được SPI một cách ổn định, hoặc jitter khi có camera + NPU làm vòng rate 1 kHz lỡ chu kỳ, hoặc không tạo được tín hiệu ESC đủ chính xác. Phần mềm Linux và định dạng IPC giữ nguyên; chỉ đổi đường truyền từ RAM chung sang UART.

## 6. Bước tiếp theo: Milestone 2 (chờ bạn duyệt)

### Phần cứng cần có

- Module ICM-42688-P (SPI, 3,3 V)
- Máy hiện sóng hoặc logic analyzer cho SPI loopback và PWM
- Dây nối MOSI–MISO (chân 8–9) để test loopback

### Thứ tự làm

- Mô tả thiết bị SPI0 cho HAL MCU, giữ clock SPI0 trong node rockchip,amp
- Loopback 1 / 5 / 10 MHz, rồi đọc WHO_AM_I của IMU
- Đọc IMU 1 kHz → estimator → PID → mixer ảo; đo thời gian tính mỗi vòng
- Chạy thử vòng lặp từ hpmcu_sram để so jitter

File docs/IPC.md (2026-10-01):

# Linux ↔ MCU: vendor có gì

Viết tắt như [RV1103_MCU.md](RV1103_MCU.md).

| Cơ chế | Có cho RV1106 không | Bằng chứng |
|---|---|---|
| RPMsg (kernel) | **không** | `K/drivers/rpmsg/rockchip_rpmsg.c:402-404` chỉ khớp `rk3562-rpmsg`, `rk3568-rpmsg` |
| rpmsg-lite (MCU) | **không** | `MCU/bsp/rockchip/common/drivers/rpmsg-lite/lib/include/platform/`: RK3308, RK3568, i.MX…, không có RV1106 |
| remoteproc | không bật | `objs_kernel/.config`: `# CONFIG_REMOTEPROC is not set` |
| Mailbox framework (kernel) | không bật | `# CONFIG_MAILBOX is not set` |
| Mailbox phần cứng | có | `DTS/rv1106.dtsi:1116` (0xFF5C0000); MCU có ngắt `MAILBOX0_AP/BB` (`soc.h:58-59`); HAL `hal_mbox.c` |
| pstore/ramoops đọc log MCU | có trong thiết kế TB, **tắt** trên Luckfox | `DTS/rv1106-thunder-boot.dtsi:26-35`; `# CONFIG_PSTORE is not set` |
| `/dev/mem` | có | `CONFIG_DEVMEM=y`, `# CONFIG_STRICT_DEVMEM is not set` |

## Milestone 1

Chỉ có kênh một chiều MCU → Linux qua RAM chung (đã chừa bằng `reserved-memory`):
- log: vòng đệm `drv_pstore.c` tại `MCU_LOG_BASE`
- số liệu: `struct mcu_bench_shared` tại `MCU_BENCH_BASE` (`shared/ipc/mcu_bench_shared.h`), đọc nhất quán bằng số thứ tự `seq`

Cache: MCU gọi `HAL_DCACHE_CleanByRange` sau khi ghi (nếu `HAL_DCACHE_MODULE_ENABLED`). MCU có bật D-cache cho DDR không:
**UNKNOWN** (không thấy `HAL_DCACHE_Enable` trong BSP). Linux map vùng `no-map` qua `/dev/mem` với `O_SYNC`.

## Kênh điều khiển (2026-10-01): `shared/ipc/fc_ipc.{h,c}`

Dùng polling, không dùng mailbox (kernel không bật `CONFIG_MAILBOX`):
- **Vị trí:** trang 4 KB tại `MCU_IPC_BASE` = `0x0183F000`. Đây là chính trang benchmark của M1, nên DTS hiện tại đã giữ riêng sẵn, không phải nạp lại Linux. Mỗi firmware dùng trang này cho benchmark hoặc cho IPC, không bao giờ cả hai.
- **Hai vòng đệm SPSC, mỗi vòng 16 bản ghi 64 byte:**
  - `down`: Linux → MCU, chở lệnh lái (kênh CRSF) và heartbeat.
  - `up`: MCU → Linux, chở telemetry.
- **Chỉ số head/tail:** mỗi chỉ số do đúng một bên ghi, và nằm trên dòng 64 byte riêng.
- **Chống đọc dở:** mỗi bản ghi có `seq` và CRC-16. Bản ghi rách hoặc cũ bị bỏ, không bao giờ được dùng.
- **Cache:**
  - MCU gọi `HAL_DCACHE_CleanByRange` sau khi ghi và `HAL_DCACHE_InvalidateByRange` trước khi đọc (`hal_conf.h` bật `HAL_DCACHE_MODULE_ENABLED`).
  - Linux map `/dev/mem` với `O_SYNC`.
- **Chưa kiểm chứng trên board:** MCU có thật sự bật D-cache cho DDR không vẫn **UNKNOWN**; hàm invalidate/clean làm đúng trong cả hai trường hợp.
- **Kiểm thử:** unit test trong `mcu/tests/test_flight.c` (`test_ipc`), chuỗi đầy đủ trong `ground/test_chain.py`.

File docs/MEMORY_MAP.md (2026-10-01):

# Memory map liên quan tới HPMCU

Viết tắt như [RV1103_MCU.md](RV1103_MCU.md). Không có địa chỉ nào được chọn mà không nêu lý do và cách kiểm chứng.

## DDR 64 MB (0x0000_0000 – 0x03FF_FFFF), ai dùng gì lúc boot

| Vùng | Người dùng | Nguồn |
|---|---|---|
| 0x0 – 0x28000 | SPL (code) | `UB/include/configs/rv1106_common.h:37-38` |
| 0x1FE000 – 0x21E000 | SPL bss + stack | `rv1106_common.h:39-41` |
| 0x200000, 178 KB | U-Boot (ảnh FIT) | `rv1106_common.h:22`; `dumpimage -l images/uboot.img` |
| 0x8000 → | kernel được nạp (`kernel_addr_r`) | `rv1106_common.h:81` |
| 0x8000 – 0x78C364 | kernel sau khi chạy (`_text` … `_end`) | `K/arch/arm/Makefile:141` (textofs 0x8000), `objs_kernel/System.map` (`_text=b0008000`, `_end=b078c364`), `CONFIG_AUTO_ZRELADDR=y` |
| 0xC00000 | DTB (`fdt_addr_r`) | `rv1106_common.h:79` |
| 0xE00000 / 0xE00800 | ramdisk / `CONFIG_SYS_LOAD_ADDR` (boot.img, phân vùng 4 MB) | `rv1106_common.h:25,82`; `BoardConfig…Mini-IPC.mk:38` |
| gần đỉnh RAM | U-Boot sau relocate (malloc 16 MB) | `rv1106_common.h:15`; địa chỉ thật: **UNKNOWN**, đọc bằng `bdinfo` |
| động | CMA 24 MB của Linux | TEST `/proc/meminfo` |

## ⚠ Vùng MCU mặc định 0x40000 nằm trong kernel

`BSP/link.lds:5` đặt MCU ở 0x40000–0x7BFFF, log ở 0x7C000 (`BSP/rtconfig.h:272-273`).
Kernel chiếm 0x8000–0x78C364, **chứa trọn vùng này**. Nếu MCU chạy ở 0x40000 thì kernel ghi đè code MCU, hoặc MCU ghi đè kernel.

Chính `DTS/rv1106-thunder-boot.dtsi:22-24` của Rockchip cũng khai báo `rtos@40000`. Mình chưa giải thích được thiết kế TB
sống chung với kernel ở 0x8000 thế nào: **UNKNOWN — NEED VERIFICATION**. Kết luận cho repo: **không dùng 0x40000**.

## Vùng MCU của repo (đã kiểm chứng trên board 2026-09-24)

Nguồn duy nhất: `shared/ipc/mcu_layout.h`. Các chỗ phải khớp được `tools/build_mcu.sh` kiểm tra khi build.

| Vùng | Địa chỉ | Kích thước | Dùng cho |
|---|---|---|---|
| code + data + heap | 0x0180_0000 | 0x3C000 | `rtthread.bin` (entry 0x1800200) |
| log | 0x0183_C000 | 0x3000 | vòng đệm `drv_pstore.c` (`CONFIG_PERSISTENT_RAM_ADDR`) |
| benchmark **hoặc** IPC | 0x0183_F000 | 0x1000 | `struct mcu_bench_shared` (M1) hoặc `struct fc_ipc_page` (firmware bay, `MCU_IPC_BASE`) |

Lý do chọn 0x01800000: nằm ngoài mọi vùng đã liệt kê ở bảng trên (trên boot.img ≤ 0x1200800, dưới vùng U-Boot relocate).
Được Linux chừa ra bằng `reserved-memory … no-map` trong `linux/dts/rv1103g-luckfox-pico-mini-m1.dts`.

| Kiểm tra | Kết quả trên board (firmware M1) |
|---|---|
| `/proc/device-tree/reserved-memory/mcu@1800000/reg` | `01 80 00 00 00 04 00 00` ✓ |
| `/proc/iomem` | System RAM `00000000-017fffff` và `01840000-03ffffff`: vùng MCU bị loại ✓ |
| Kernel thật sự nằm ở đâu | `Kernel code 00008000-006befff`, `Kernel data 006f6000-0078c363` (xác nhận vùng 0x40000 của SDK nằm trong kernel) |
| MemTotal | 32 596 → 32 336 kB (giảm 256 KB) ✓ |
| U-Boot (UART) | `Relocation Offset: 03d80000` → U-Boot ở 0x03F80000; `Relocation fdt: 02df9f58 - 02dfede8` ✓ (trên 0x01840000). Chưa chạy được `bdinfo` để thấy đầu vùng malloc |
| `mcu-tool load` | đọc lại firmware khớp từng byte ✓ |

Log: `logs/m1_uart_boot1.txt`.

## SRAM và thanh ghi

| Vùng | Địa chỉ | Nguồn |
|---|---|---|
| system_sram | 0xFF6C0000, 256 KB | `DTS/rv1106.dtsi:1140` |
| hpmcu_sram | 0xFF6FE000, 8 KB | `DTS/rv1106.dtsi:1149` |
| Mailbox (A7↔MCU) | 0xFF5C0000 | `DTS/rv1106.dtsi:1116` |
| PMU mailbox | 0xFF378000 | `DTS/rv1106.dtsi:666` |
| INT_MUX | 0xFF5D0000 | `BSP/drivers/int_mux.h:20` |

Thanh ghi điều khiển MCU: [RV1103_MCU.md §3](RV1103_MCU.md).

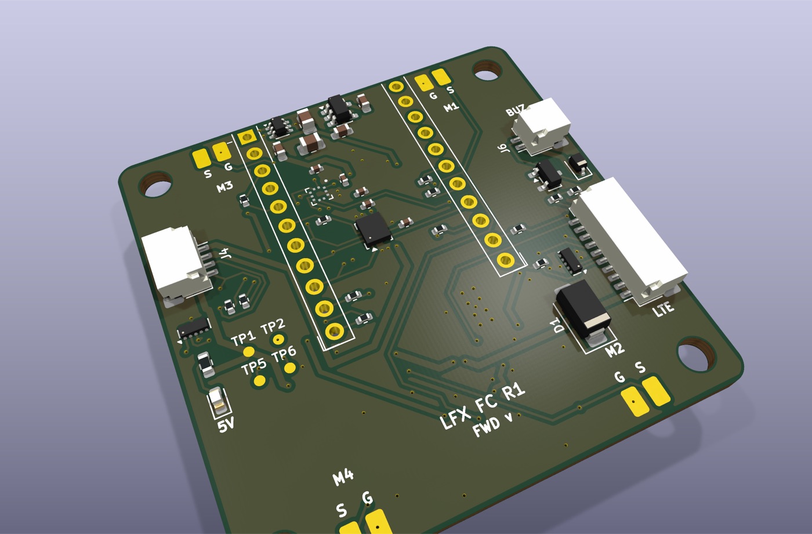
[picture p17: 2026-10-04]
docs/img/pcb/3d_iso.jpg

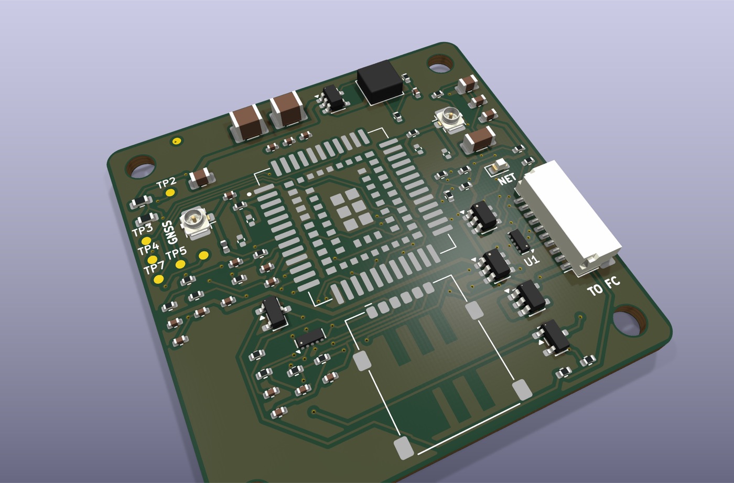
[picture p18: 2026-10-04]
docs/img/pcb/lte_3d_iso.jpg

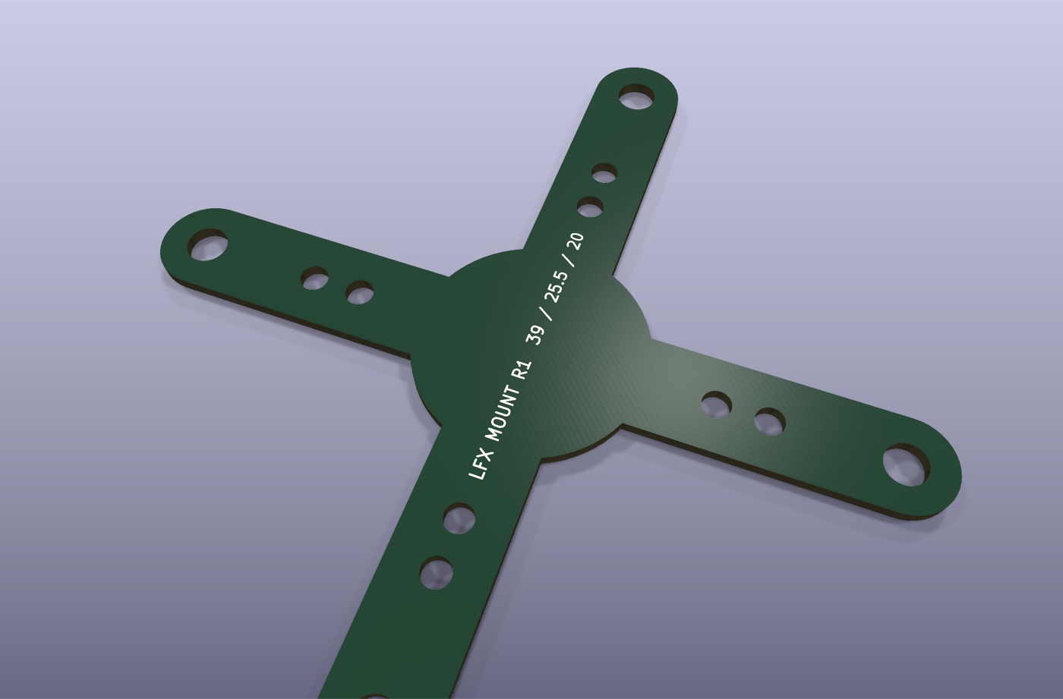
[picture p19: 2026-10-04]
docs/img/pcb/mount_3d_iso.jpg

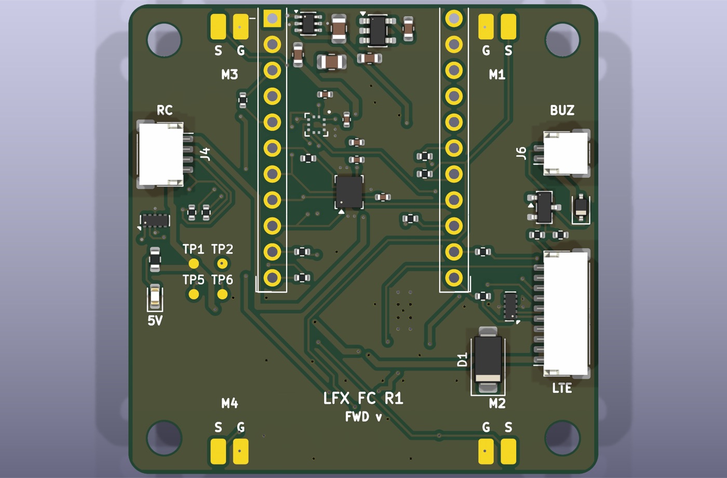
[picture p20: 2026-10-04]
docs/img/pcb/3d_top.jpg

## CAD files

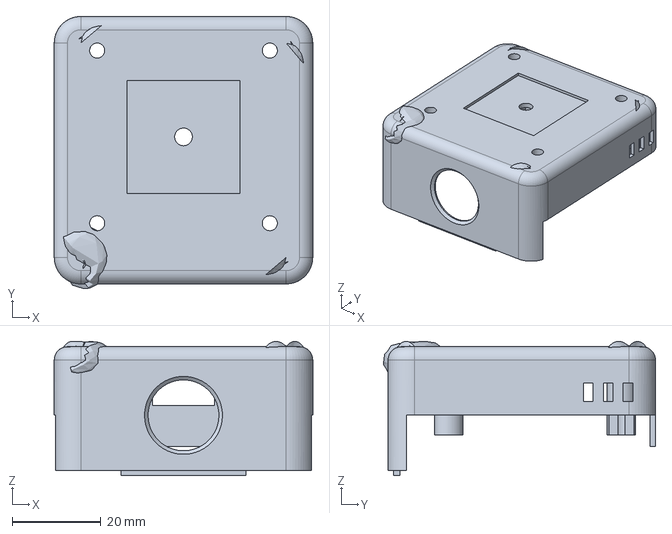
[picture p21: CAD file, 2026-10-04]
hardware/LFX_CANOPY_R1/canopy.step
58.4 x 61.4 x 30.3 mm

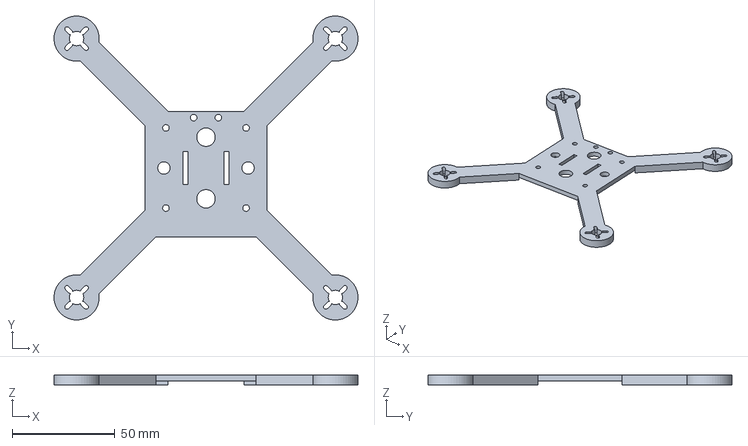
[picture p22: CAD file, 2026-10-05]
hardware/LFX_FRAME_R1/frame.step
148.0 x 148.0 x 5.00 mm

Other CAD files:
hardware/LFX_CANOPY_R1/canopy.stl
hardware/LFX_FRAME_R1/frame.stl

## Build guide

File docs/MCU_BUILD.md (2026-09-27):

# Build firmware MCU

Yêu cầu: đã chạy `./run.sh build` ít nhất một lần (tạo image `luckfox-build:22.04` và volume `luckfox-src`).

```sh
tools/build_mcu.sh luckfox_mini-M1-NONE      # Milestone 1: hello + vòng lặp 1 kHz, chạy ở 0x01800000
tools/build_mcu.sh luckfox_mini-FC-NONE      # code bay (mcu/) + SIM_SENSOR + mô hình quad chạy trên MCU, đo chu kỳ CPU
tools/run_fc_mcu.sh 60                       # nạp lên board qua SSH/ADB, chạy 60 s, lưu log vào logs/
tools/build_mcu.sh luckfox_mini-HELLO-NONE   # hello world ở vị trí mặc định 0x40000 (không chạy song song Linux được)
tools/build_mcu.sh rv1106_evb-SC3338-ADC     # board mẫu của Rockchip, nguyên bản
```

Script làm:
1. Lần đầu tạo image `luckfox-build:22.04-mcu` = image gốc + `scons` (image gốc không bị sửa).
2. Chép `mcu/bsp/<board>` và `shared/ipc/*.h` vào `BSP/board/<board>` trong volume SDK.
3. Nếu board có `mcu_region.env`: kiểm tra địa chỉ khớp `shared/ipc/mcu_layout.h` và `CONFIG_PERSISTENT_RAM_ADDR`,
   rồi tạm đổi `ORIGIN` trong `BSP/link.lds`. Bản gốc lưu ở `link.lds.sdk` và được trả lại khi build xong, kể cả khi lỗi.
4. Chạy đúng lệnh SDK: `./build.sh mcu <board>` (`project/build.sh:876-919`).
5. Chép `rtthread.{bin,elf,map}` ra `out/mcu/<board>/`, log vào `logs/mcu_<board>.log`.

Board có file `FLIGHT_CORE` (luckfox_mini-FC-NONE) được chép thêm code bay vào `tree/` theo đúng
cấu trúc repo (`tree/mcu/*`, `tree/shared/rc`, `tree/simulator/{quad_model,sim_sensors}`), nên
`#include` tương đối trong code bay không phải sửa. Bản build 2026-09-27: text 53 132 B, chỉ có
soft-float đơn (`__mulsf3`, `__addsf3`, …), không có `__*df3` (không lọt phép double nào).

Tên board phải có dạng `Board-Sensor-LightSensor` (3 phần ngăn bởi `-`), nếu không `mcu/build.sh lunch` báo "Not found".

Kết quả đã kiểm tra:

| Board | `rtthread.bin` | text / data / bss | entry |
|---|---|---|---|
| luckfox_mini-M1-NONE | 22 072 B | 21 883 / 160 / 223 688 | 0x1800200 |
| luckfox_mini-HELLO-NONE | 18 256 B | 18 080 / 148 / 227 504 | 0x40200 |
| rv1106_evb-SC3338-ADC | 114 516 B | | 0x40200 |

`bss` lớn vì heap trải hết phần còn lại của vùng 0x3C000 (`link.lds:117`, `HEAP_SIZE`).

Cấu trúc board tối thiểu: `SConscript`, `Kconfig`, `defconfig`, `board.c`, `board.h`, `iomux.c`, `iomux.h`
(`BSP/board/SConscript` nạp `board/$RT_BOARD_NAME/SConscript`). Board cần `CONFIG_RT_USING_PIN=y`, vì
`board/common/iomux_base.c` và `board_cam.c` luôn được biên dịch và cần HAL GPIO.

Công cụ Linux: `tools/build_linux_tools.sh` build `linux/mcu-tool` bằng toolchain `arm-rockchip830-linux-uclibcgnueabihf` của SDK → `out/linux-tools/mcu-tool`.

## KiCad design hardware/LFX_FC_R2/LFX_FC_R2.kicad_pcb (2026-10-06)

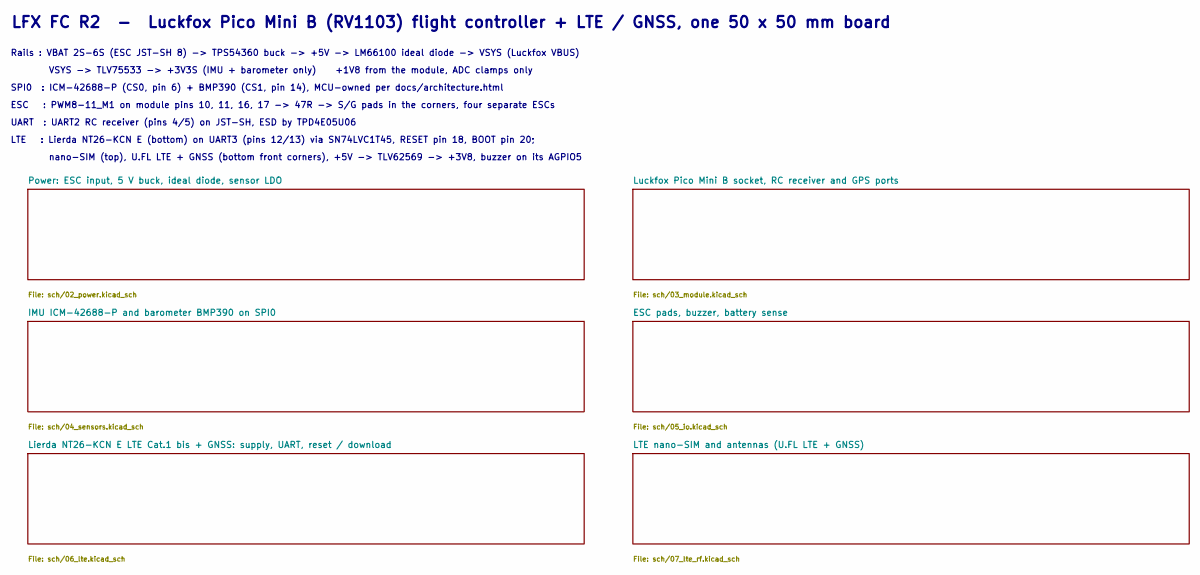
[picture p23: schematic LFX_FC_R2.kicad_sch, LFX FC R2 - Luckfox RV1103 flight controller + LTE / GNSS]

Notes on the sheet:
LFX FC R2 - Luckfox Pico Mini B (RV1103) flight controller + LTE / GNSS, one 50 x 50 mm board
Rails : VBAT 2S-6S (ESC JST-SH 8) -> TPS54360 buck -> +5V -> LM66100 ideal diode -> VSYS (Luckfox VBUS)
VSYS -> TLV75533 -> +3V3S (IMU + barometer only) +1V8 from the module, ADC clamps only
SPI0 : ICM-42688-P (CS0, pin 6) + BMP390 (CS1, pin 14), MCU-owned per docs/architecture.html
ESC : PWM8-11_M1 on module pins 10, 11, 16, 17 -> 47R -> S/G pads in the corners, four separate ESCs
UART : UART2 RC receiver (pins 4/5) on JST-SH, ESD by TPD4E05U06
LTE : Lierda NT26-KCN E (bottom) on UART3 (pins 12/13) via SN74LVC1T45, RESET pin 18, BOOT pin 20;
nano-SIM (top), U.FL LTE + GNSS (bottom front corners), +5V -> TLV62569 -> +3V8, buzzer on its AGPIO5

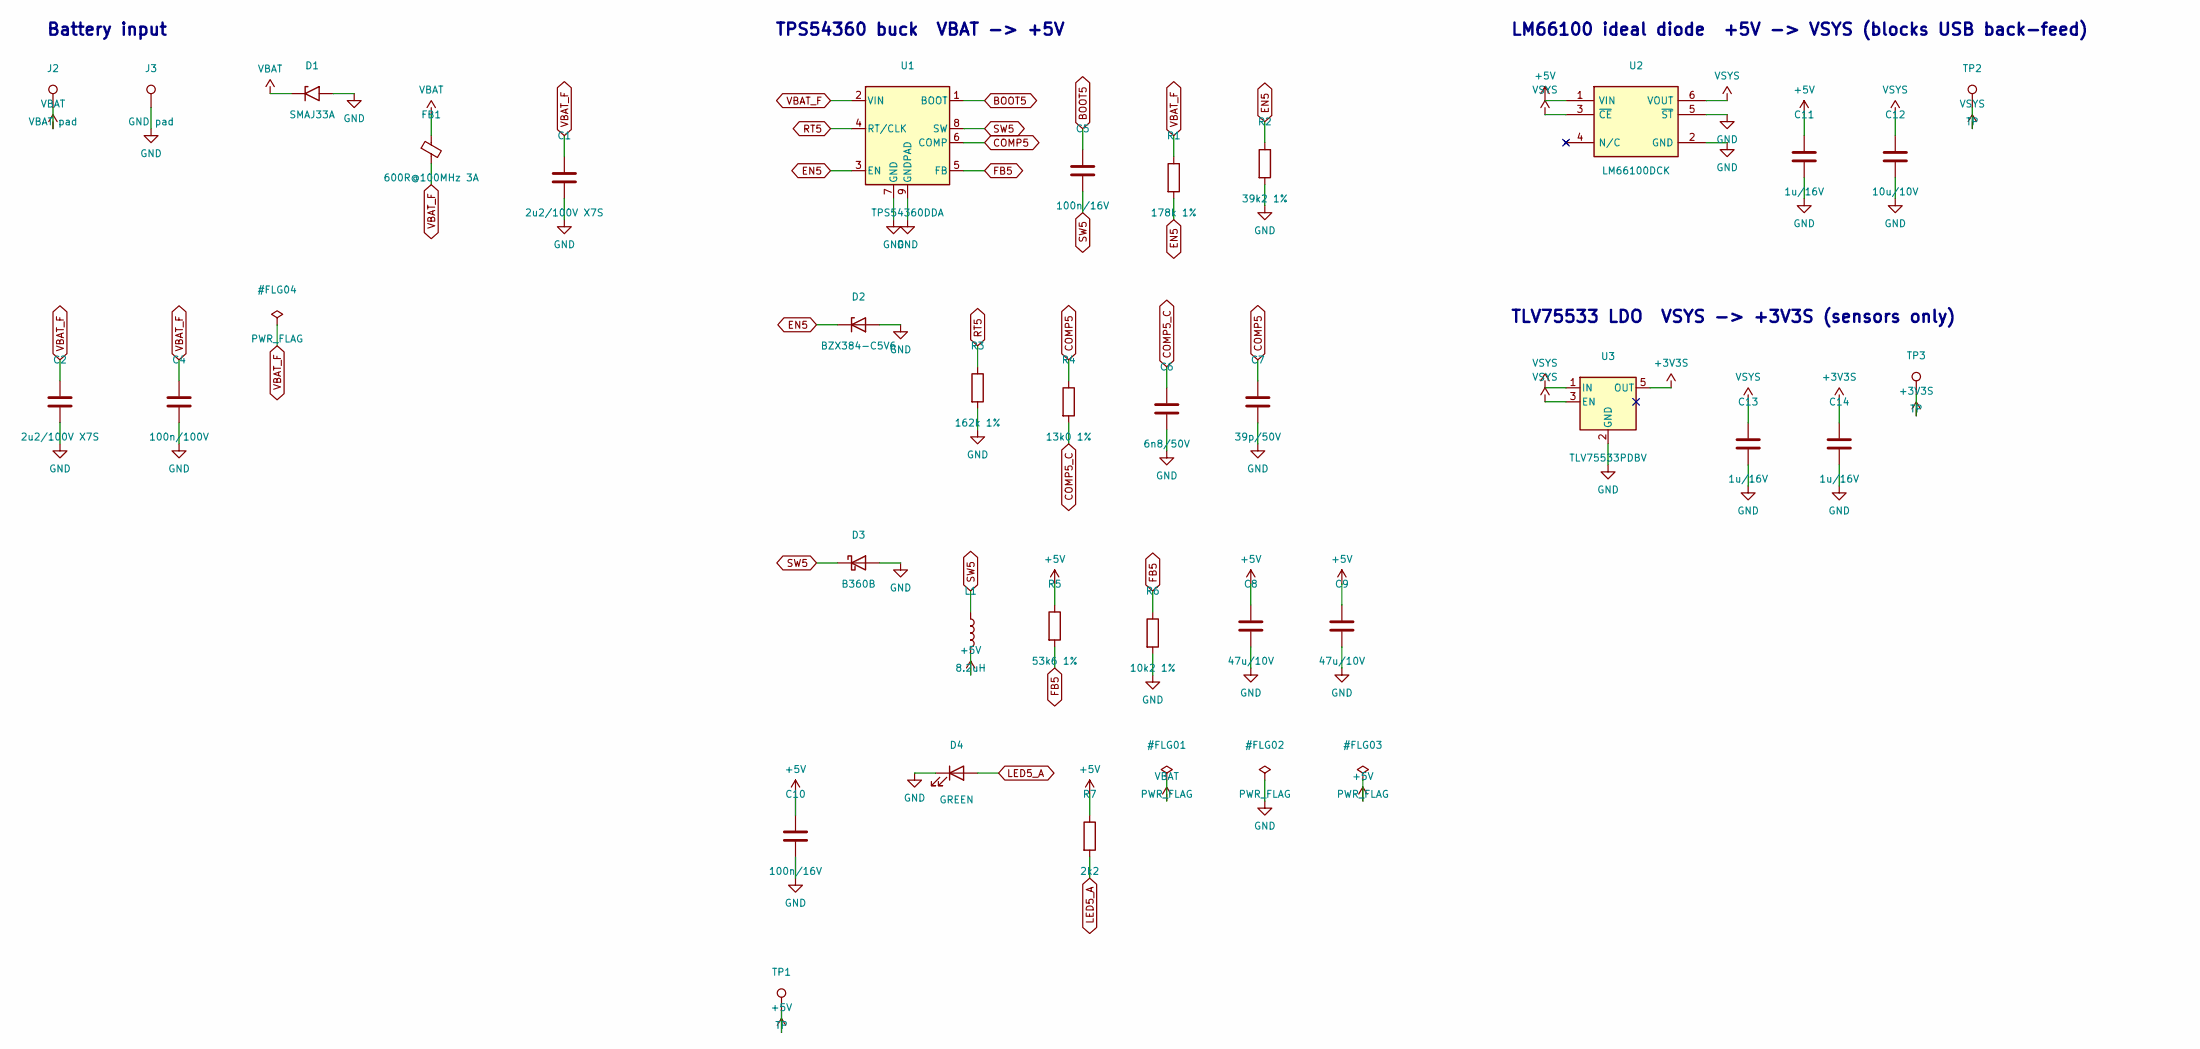
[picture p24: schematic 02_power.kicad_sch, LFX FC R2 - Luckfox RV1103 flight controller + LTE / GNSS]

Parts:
C1, C2: 2u2/100V X7S; C_1206_3216Metric
C4: 100n/100V; C_0603_1608Metric
C5, C10: 100n/16V; C_0603_1608Metric
C6: 6n8/50V; C_0402_1005Metric
C7: 39p/50V; C_0402_1005Metric
C8, C9: 47u/10V; C_1210_3225Metric
C11, C13, C14: 1u/16V; C_0603_1608Metric
C12: 10u/10V; C_0805_2012Metric
D1: SMAJ33A; D_SMA
D2: BZX384-C5V6; D_SOD-323
D3: B360B; D_SMB
D4: GREEN; LED_0603_1608Metric
FB1: 600R@100MHz 3A; L_1206_3216Metric
J2: VBAT pad; SolderPad_2.5x4mm
J3: GND pad; SolderPad_2.5x4mm
L1: 8.2uH; L_Coilcraft_XAL5050-XXX
R1: 178k 1%; R_0603_1608Metric
R2: 39k2 1%; R_0603_1608Metric
R3: 162k 1%; R_0603_1608Metric
R4: 13k0 1%; R_0402_1005Metric
R5: 53k6 1%; R_0402_1005Metric
R6: 10k2 1%; R_0402_1005Metric
R7: 2k2; R_0603_1608Metric
TP1, TP2, TP3: TP; TestPad_1.0mm
U1: TPS54360DDA; TI_SO-PowerPAD-8_ThermalVias
U2: LM66100DCK; SOT-363_SC-70-6
U3: TLV75533PDBV; SOT-23-5

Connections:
+3V3S: C14.1, TP3.1, U3.5 (OUT); also elsewhere on the board
+5V: C8.1, C9.1, C10.1, C11.1, L1.2, R5.1, R7.1, TP1.1, U2.1 (VIN); also elsewhere on the board
BOOT5: C5.1, U1.1 (BOOT)
COMP5: C7.1, R4.1, U1.6 (COMP)
COMP5_C: C6.1, R4.2
EN5: D2.1 (K), R1.2, R2.1, U1.3 (EN)
FB5: R5.2, R6.1, U1.5 (FB)
GND: C1.2, C2.2, C4.2, C6.2, C7.2, C8.2, C9.2, C10.2, C11.2, C12.2, C13.2, C14.2, D1.2 (A2), D2.2 (A), D3.2 (A), D4.1 (K), J3.1, R2.2, R3.2, R6.2, U1.7 (GND), U1.9 (GNDPAD), U2.2 (GND), U2.5 (~ST), U3.2 (GND); also elsewhere on the board
LED5_A: D4.2 (A), R7.2
RT5: R3.1, U1.4 (RT/CLK)
SW5: C5.2, D3.1 (K), L1.1, U1.8 (SW)
VBAT: D1.1 (A1), FB1.1, J2.1; also elsewhere on the board
VBAT_F: C1.1, C2.1, C4.1, FB1.2, R1.1, U1.2 (VIN)
VSYS: C12.1, C13.1, TP2.1, U2.3 (~CE), U2.6 (VOUT), U3.1 (IN), U3.3 (EN); also elsewhere on the board

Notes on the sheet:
Battery input
TPS54360 buck VBAT -> +5V
LM66100 ideal diode +5V -> VSYS (blocks USB back-feed)
TLV75533 LDO VSYS -> +3V3S (sensors only)

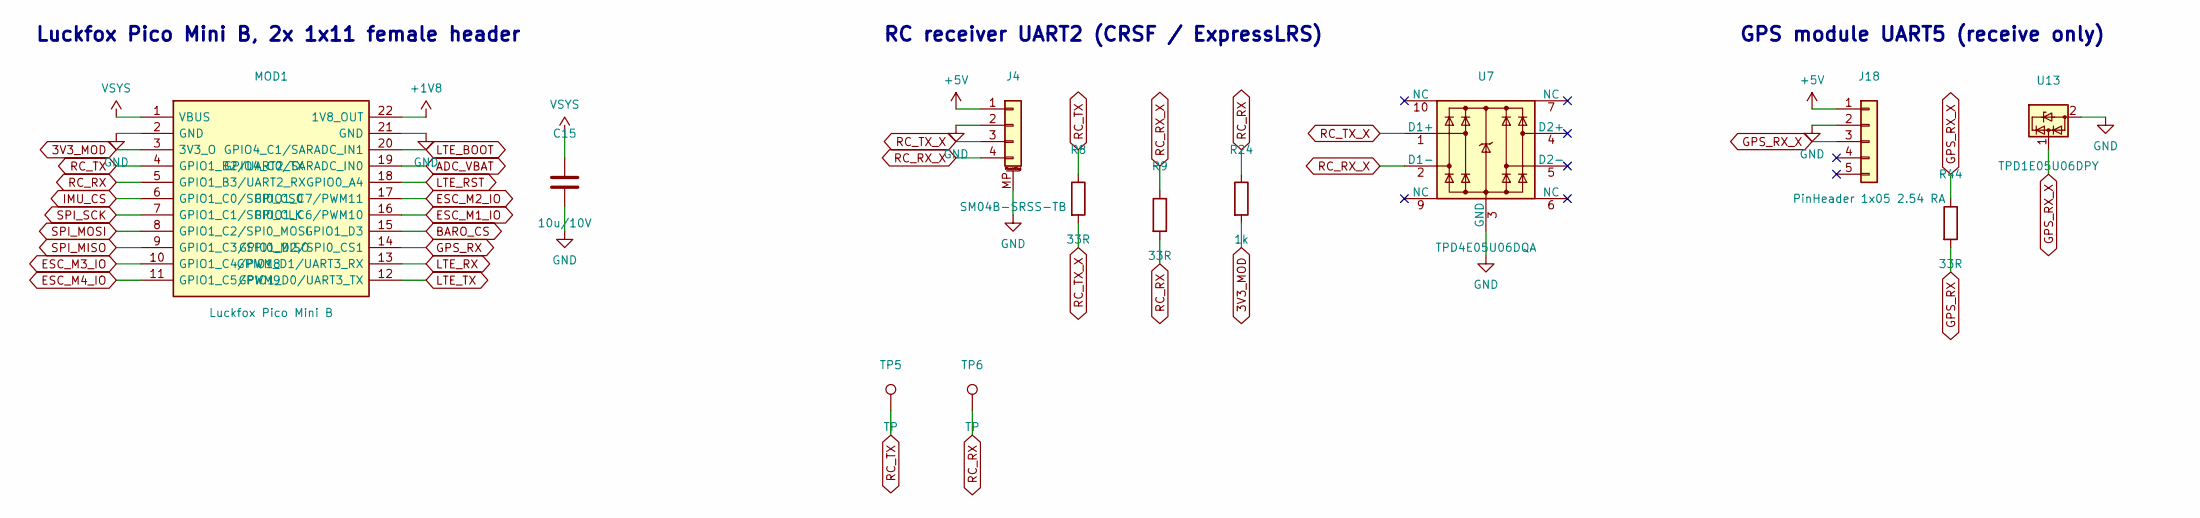
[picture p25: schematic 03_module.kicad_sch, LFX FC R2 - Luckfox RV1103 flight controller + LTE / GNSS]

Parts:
C15: 10u/10V; C_0805_2012Metric
J4: SM04B-SRSS-TB; JST_SH_SM04B-SRSS-TB_1x04-1MP_P1.00mm_Horizontal
J18: PinHeader 1x05 2.54 RA; PinHeader_1x05_P2.54mm_EdgeHorizontal
MOD1: Luckfox Pico Mini B; Luckfox_Pico_Mini_Socket
R8, R9, R44: 33R; R_0402_1005Metric
R24: 1k; R_0402_1005Metric
TP5, TP6: TP; TestPad_1.0mm
U7: TPD4E05U06DQA; USON-10_2.5x1.0mm_P0.5mm
U13: TPD1E05U06DPY; Texas_DPY0002A_0.6x1mm_P0.65mm

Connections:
3V3_MOD: MOD1.3 (3V3_O), R24.2; also elsewhere on the board
+1V8: MOD1.22 (1V8_OUT); also elsewhere on the board
+5V: J4.1, J18.1; also elsewhere on the board
ADC_VBAT: MOD1.19 (GPIO4_C0/SARADC_IN0); also elsewhere on the board
BARO_CS: MOD1.15 (GPIO1_D3); also elsewhere on the board
ESC_M1_IO: MOD1.16 (GPIO1_C6/PWM10); also elsewhere on the board
ESC_M2_IO: MOD1.17 (GPIO1_C7/PWM11); also elsewhere on the board
ESC_M3_IO: MOD1.10 (GPIO1_C4/PWM8); also elsewhere on the board
ESC_M4_IO: MOD1.11 (GPIO1_C5/PWM9); also elsewhere on the board
GND: C15.2, J4.2, J4.MP (MountPin), J18.2, MOD1.2 (GND), MOD1.21 (GND), U7.3 (GND), U7.8 (GND), U13.2 (GND); also elsewhere on the board
GPS_RX: MOD1.14 (GPIO1_D2/SPI0_CS1), R44.2
GPS_RX_X: J18.3, R44.1, U13.1 (I/O)
IMU_CS: MOD1.6 (GPIO1_C0/SPI0_CS0); also elsewhere on the board
LTE_BOOT: MOD1.20 (GPIO4_C1/SARADC_IN1); also elsewhere on the board
LTE_RST: MOD1.18 (GPIO0_A4); also elsewhere on the board
LTE_RX: MOD1.13 (GPIO1_D1/UART3_RX); also elsewhere on the board
LTE_TX: MOD1.12 (GPIO1_D0/UART3_TX); also elsewhere on the board
RC_RX: MOD1.5 (GPIO1_B3/UART2_RX), R9.2, R24.1, TP6.1
RC_RX_X: J4.4, R9.1, U7.2 (D1-)
RC_TX: MOD1.4 (GPIO1_B2/UART2_TX), R8.1, TP5.1
RC_TX_X: J4.3, R8.2, U7.1 (D1+)
SPI_MISO: MOD1.9 (GPIO1_C3/SPI0_MISO); also elsewhere on the board
SPI_MOSI: MOD1.8 (GPIO1_C2/SPI0_MOSI); also elsewhere on the board
SPI_SCK: MOD1.7 (GPIO1_C1/SPI0_CLK); also elsewhere on the board
VSYS: C15.1, MOD1.1 (VBUS); also elsewhere on the board

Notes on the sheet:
Luckfox Pico Mini B, 2x 1x11 female header
RC receiver UART2 (CRSF / ExpressLRS)
GPS module UART5 (receive only)

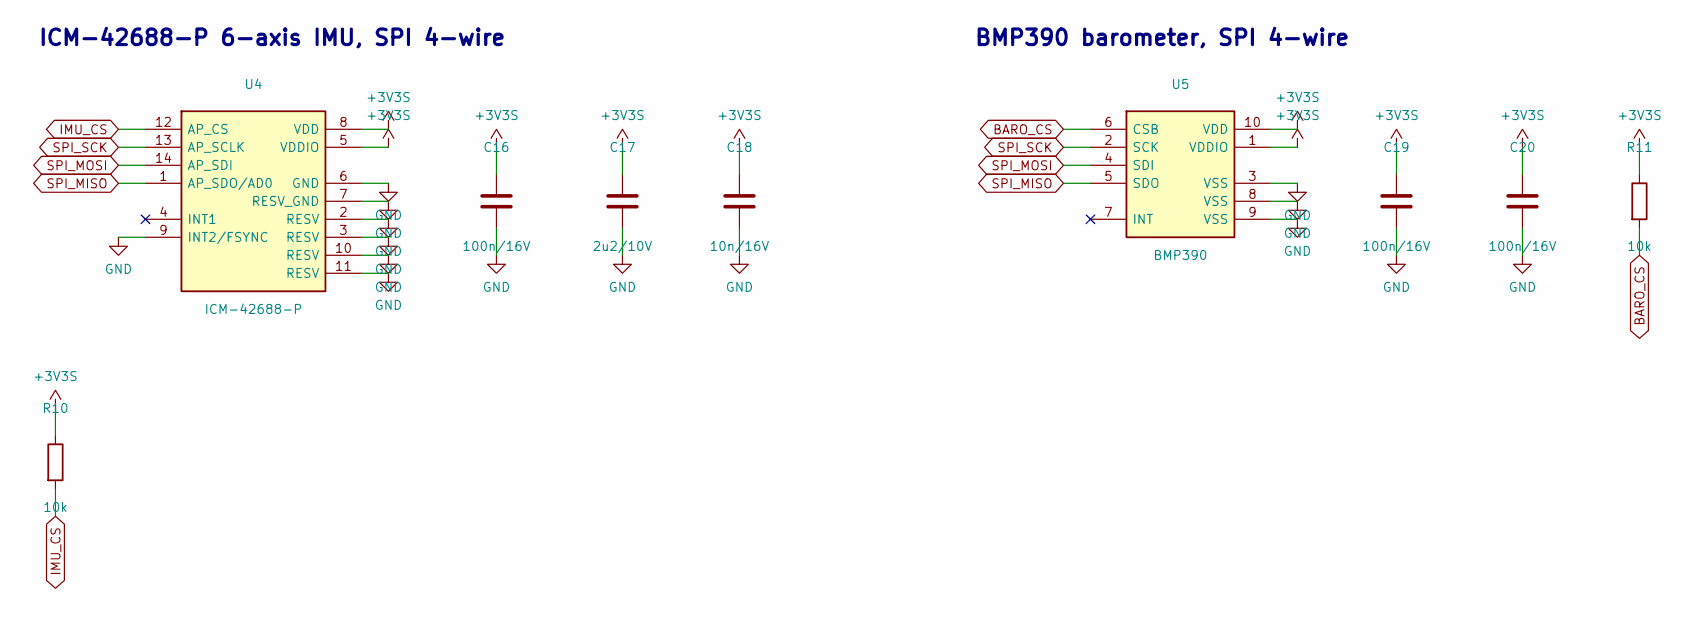
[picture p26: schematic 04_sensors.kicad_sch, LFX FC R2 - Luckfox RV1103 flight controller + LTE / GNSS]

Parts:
C16, C19, C20: 100n/16V; C_0402_1005Metric
C17: 2u2/10V; C_0402_1005Metric
C18: 10n/16V; C_0402_1005Metric
R10, R11: 10k; R_0402_1005Metric
U4: ICM-42688-P; LGA-14_3x2.5mm_P0.5mm_LayoutBorder3x4y
U5: BMP390; Bosch_BMP390_LGA-10_2x2mm_P0.5mm

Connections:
+3V3S: C16.1, C17.1, C18.1, C19.1, C20.1, R10.1, R11.1, U4.5 (VDDIO), U4.8 (VDD), U5.1 (VDDIO), U5.10 (VDD); also elsewhere on the board
BARO_CS: R11.2, U5.6 (CSB); also elsewhere on the board
GND: C16.2, C17.2, C18.2, C19.2, C20.2, U4.2 (RESV), U4.3 (RESV), U4.6 (GND), U4.7 (RESV_GND), U4.9 (INT2/FSYNC), U4.10 (RESV), U4.11 (RESV), U5.3 (VSS), U5.8 (VSS), U5.9 (VSS); also elsewhere on the board
IMU_CS: R10.2, U4.12 (AP_CS); also elsewhere on the board
SPI_MISO: U4.1 (AP_SDO/AD0), U5.5 (SDO); also elsewhere on the board
SPI_MOSI: U4.14 (AP_SDI), U5.4 (SDI); also elsewhere on the board
SPI_SCK: U4.13 (AP_SCLK), U5.2 (SCK); also elsewhere on the board

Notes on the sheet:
ICM-42688-P 6-axis IMU, SPI 4-wire
BMP390 barometer, SPI 4-wire

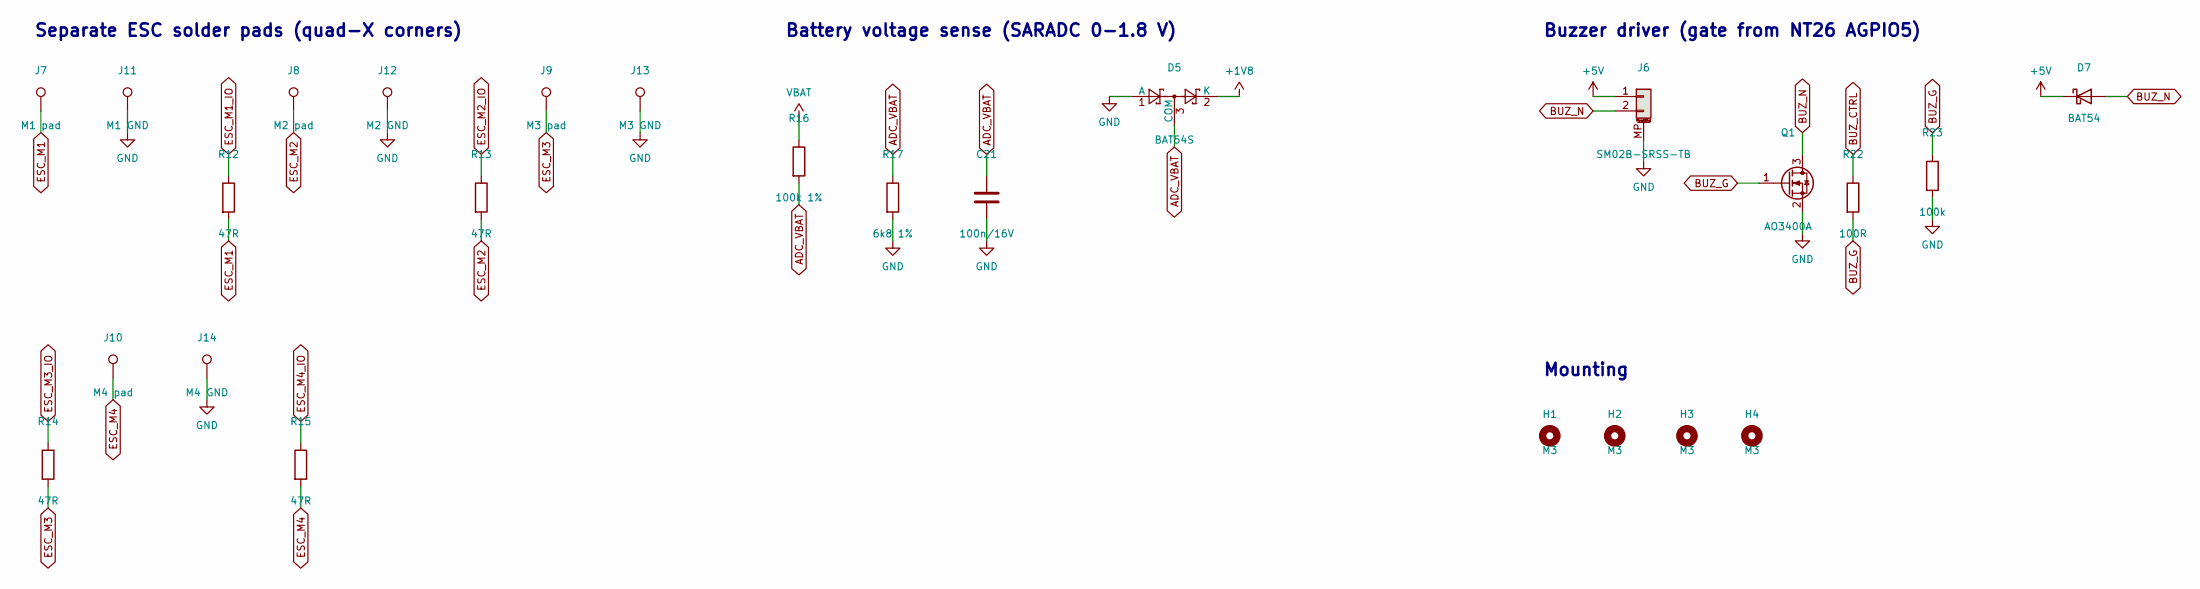
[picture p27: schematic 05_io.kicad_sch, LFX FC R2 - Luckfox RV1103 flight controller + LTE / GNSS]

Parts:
C21: 100n/16V; C_0402_1005Metric
D5: BAT54S; SOT-23
D7: BAT54; D_SOD-323
H1, H2, H3, H4: M3; MountingHole_3.2mm_M3
J6: SM02B-SRSS-TB; JST_SH_SM02B-SRSS-TB_1x02-1MP_P1.00mm_Horizontal
J7: M1 pad; SolderPad_1.5x2.5mm
J8: M2 pad; SolderPad_1.5x2.5mm
J9: M3 pad; SolderPad_1.5x2.5mm
J10: M4 pad; SolderPad_1.5x2.5mm
J11: M1 GND; SolderPad_1.5x2.5mm
J12: M2 GND; SolderPad_1.5x2.5mm
J13: M3 GND; SolderPad_1.5x2.5mm
J14: M4 GND; SolderPad_1.5x2.5mm
Q1: AO3400A; SOT-23
R12, R13, R14, R15: 47R; R_0402_1005Metric
R16: 100k 1%; R_0603_1608Metric
R17: 6k8 1%; R_0603_1608Metric
R22: 100R; R_0402_1005Metric
R23: 100k; R_0402_1005Metric

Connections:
+1V8: D5.2 (K); also elsewhere on the board
+5V: D7.1 (K), J6.1; also elsewhere on the board
ADC_VBAT: C21.1, D5.3 (COM), R16.2, R17.1; also elsewhere on the board
BUZ_CTRL: R22.1; also elsewhere on the board
BUZ_G: Q1.1 (G), R22.2, R23.1
BUZ_N: D7.2 (A), J6.2, Q1.3 (D)
ESC_M1: J7.1, R12.2
ESC_M1_IO: R12.1; also elsewhere on the board
ESC_M2: J8.1, R13.2
ESC_M2_IO: R13.1; also elsewhere on the board
ESC_M3: J9.1, R14.2
ESC_M3_IO: R14.1; also elsewhere on the board
ESC_M4: J10.1, R15.2
ESC_M4_IO: R15.1; also elsewhere on the board
GND: C21.2, D5.1 (A), J6.MP (MountPin), J11.1, J12.1, J13.1, J14.1, Q1.2 (S), R17.2, R23.2; also elsewhere on the board
VBAT: R16.1; also elsewhere on the board

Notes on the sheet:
Separate ESC solder pads (quad-X corners)
Battery voltage sense (SARADC 0-1.8 V)
Buzzer driver (gate from NT26 AGPIO5)
Mounting

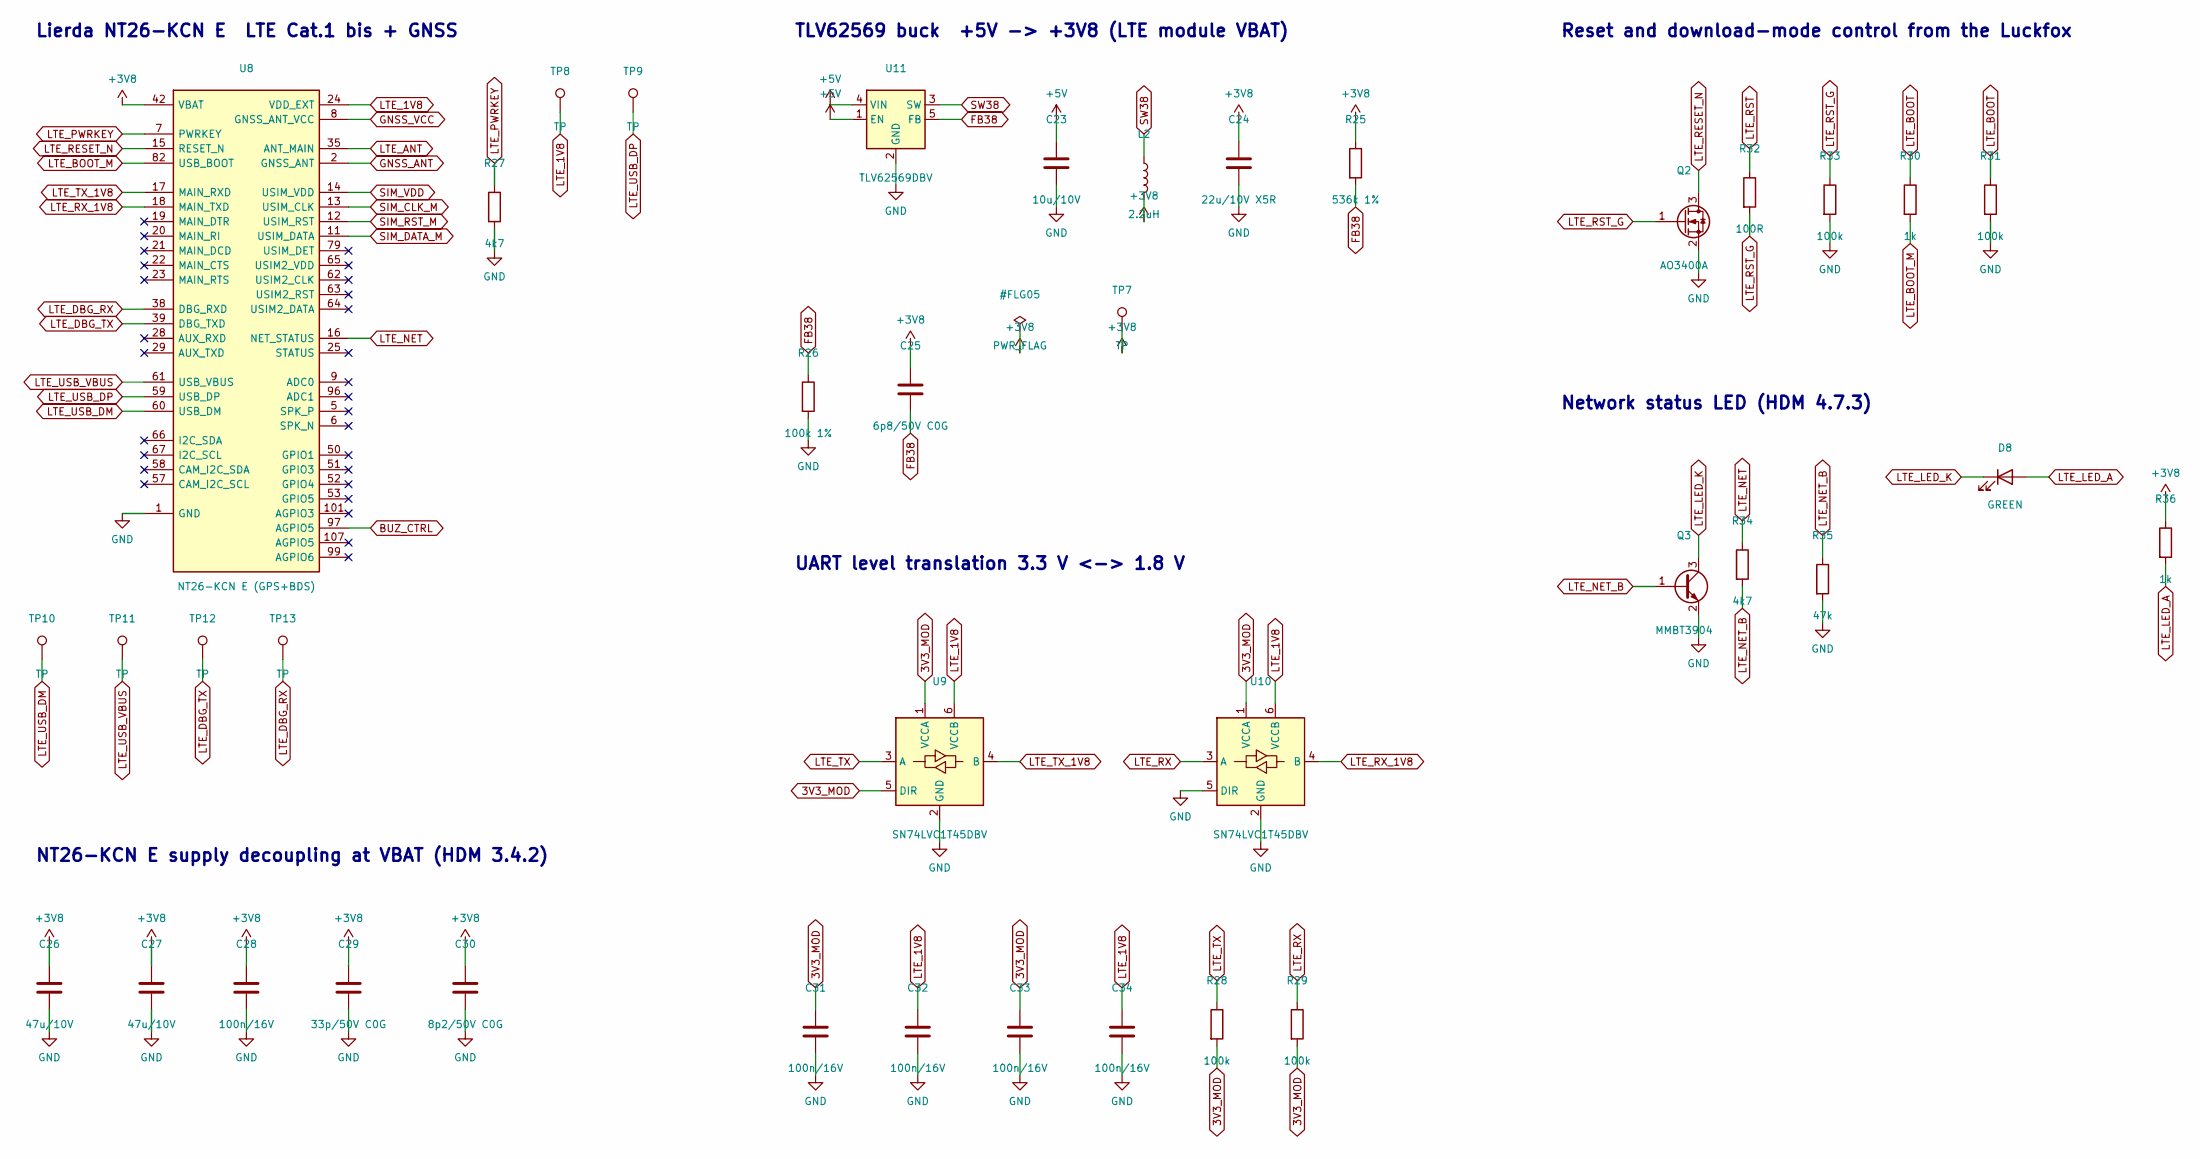
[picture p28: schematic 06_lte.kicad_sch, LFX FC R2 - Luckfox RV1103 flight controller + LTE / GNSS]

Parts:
C23: 10u/10V; C_0805_2012Metric
C24: 22u/10V X5R; C_1206_3216Metric
C25: 6p8/50V C0G; C_0402_1005Metric
C26, C27: 47u/10V; C_1210_3225Metric
C28, C31, C32, C33, C34: 100n/16V; C_0402_1005Metric
C29: 33p/50V C0G; C_0402_1005Metric
C30: 8p2/50V C0G; C_0402_1005Metric
D8: GREEN; LED_0603_1608Metric
L2: 2.2uH; L_Coilcraft_XAL4020-XXX
Q2: AO3400A; SOT-23
Q3: MMBT3904; SOT-23
R25: 536k 1%; R_0402_1005Metric
R26: 100k 1%; R_0402_1005Metric
R27, R34: 4k7; R_0402_1005Metric
R28, R29, R31, R33: 100k; R_0402_1005Metric
R30, R36: 1k; R_0402_1005Metric
R32: 100R; R_0402_1005Metric
R35: 47k; R_0402_1005Metric
TP7, TP8, TP9, TP10, TP11, TP12, TP13: TP; TestPad_1.0mm
U8: NT26-KCN E (GPS+BDS); Lierda_NT26-KCN_LCC-LGA-109_15.8x17.7mm
U9, U10: SN74LVC1T45DBV; SOT-23-6
U11: TLV62569DBV; SOT-23-5

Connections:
3V3_MOD: C31.1, C33.1, R28.2, R29.2, U9.1 (VCCA), U9.5 (DIR), U10.1 (VCCA); also elsewhere on the board
+3V8: C24.1, C25.1, C26.1, C27.1, C28.1, C29.1, C30.1, L2.2, R25.1, R36.1, TP7.1, U8.42 (VBAT), U8.43 (VBAT)
+5V: C23.1, U11.1 (EN), U11.4 (VIN); also elsewhere on the board
BUZ_CTRL: U8.97 (AGPIO5); also elsewhere on the board
FB38: C25.2, R25.2, R26.1, U11.5 (FB)
GND: C23.2, C24.2, C26.2, C27.2, C28.2, C29.2, C30.2, C31.2, C32.2, C33.2, C34.2, Q2.2 (S), Q3.2 (E), R26.2, R27.2, R31.2, R33.2, R35.2, U8.1 (GND), U8.10 (GND), U8.27 (GND), U8.34 (GND), U8.36 (GND), U8.37 (GND), U8.40 (GND), U8.41 (GND), U8.45 (GND), U8.46 (GND), U8.47 (GND), U8.48 (GND), U8.70 (GND), U8.71 (GND), U8.72 (GND), U8.73 (GND), U8.88 (GND), U8.89 (GND), U8.90 (GND), U8.91 (GND), U8.92 (GND), U8.93 (GND), U8.94 (GND), U8.95 (GND), U9.2 (GND), U10.2 (GND), U10.5 (DIR), U11.2 (GND); also elsewhere on the board
GNSS_ANT: U8.2 (GNSS_ANT); also elsewhere on the board
GNSS_VCC: U8.8 (GNSS_ANT_VCC); also elsewhere on the board
LTE_1V8: C32.1, C34.1, TP8.1, U8.24 (VDD_EXT), U9.6 (VCCB), U10.6 (VCCB)
LTE_ANT: U8.35 (ANT_MAIN); also elsewhere on the board
LTE_BOOT: R30.1, R31.1; also elsewhere on the board
LTE_BOOT_M: R30.2, U8.82 (USB_BOOT)
LTE_DBG_RX: TP13.1, U8.38 (DBG_RXD)
LTE_DBG_TX: TP12.1, U8.39 (DBG_TXD)
LTE_LED_A: D8.2 (A), R36.2
LTE_LED_K: D8.1 (K), Q3.3 (C)
LTE_NET: R34.1, U8.16 (NET_STATUS)
LTE_NET_B: Q3.1 (B), R34.2, R35.1
LTE_PWRKEY: R27.1, U8.7 (PWRKEY)
LTE_RESET_N: Q2.3 (D), U8.15 (RESET_N)
LTE_RST: R32.1; also elsewhere on the board
LTE_RST_G: Q2.1 (G), R32.2, R33.1
LTE_RX: R29.1, U10.3 (A); also elsewhere on the board
LTE_RX_1V8: U8.18 (MAIN_TXD), U10.4 (B)
LTE_TX: R28.1, U9.3 (A); also elsewhere on the board
LTE_TX_1V8: U8.17 (MAIN_RXD), U9.4 (B)
LTE_USB_DM: TP10.1, U8.60 (USB_DM)
LTE_USB_DP: TP9.1, U8.59 (USB_DP)
LTE_USB_VBUS: TP11.1, U8.61 (USB_VBUS)
SIM_CLK_M: U8.13 (USIM_CLK); also elsewhere on the board
SIM_DATA_M: U8.11 (USIM_DATA); also elsewhere on the board
SIM_RST_M: U8.12 (USIM_RST); also elsewhere on the board
SIM_VDD: U8.14 (USIM_VDD); also elsewhere on the board
SW38: L2.1, U11.3 (SW)

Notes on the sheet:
Lierda NT26-KCN E LTE Cat.1 bis + GNSS
NT26-KCN E supply decoupling at VBAT (HDM 3.4.2)
TLV62569 buck +5V -> +3V8 (LTE module VBAT)
UART level translation 3.3 V <-> 1.8 V
Reset and download-mode control from the Luckfox
Network status LED (HDM 4.7.3)

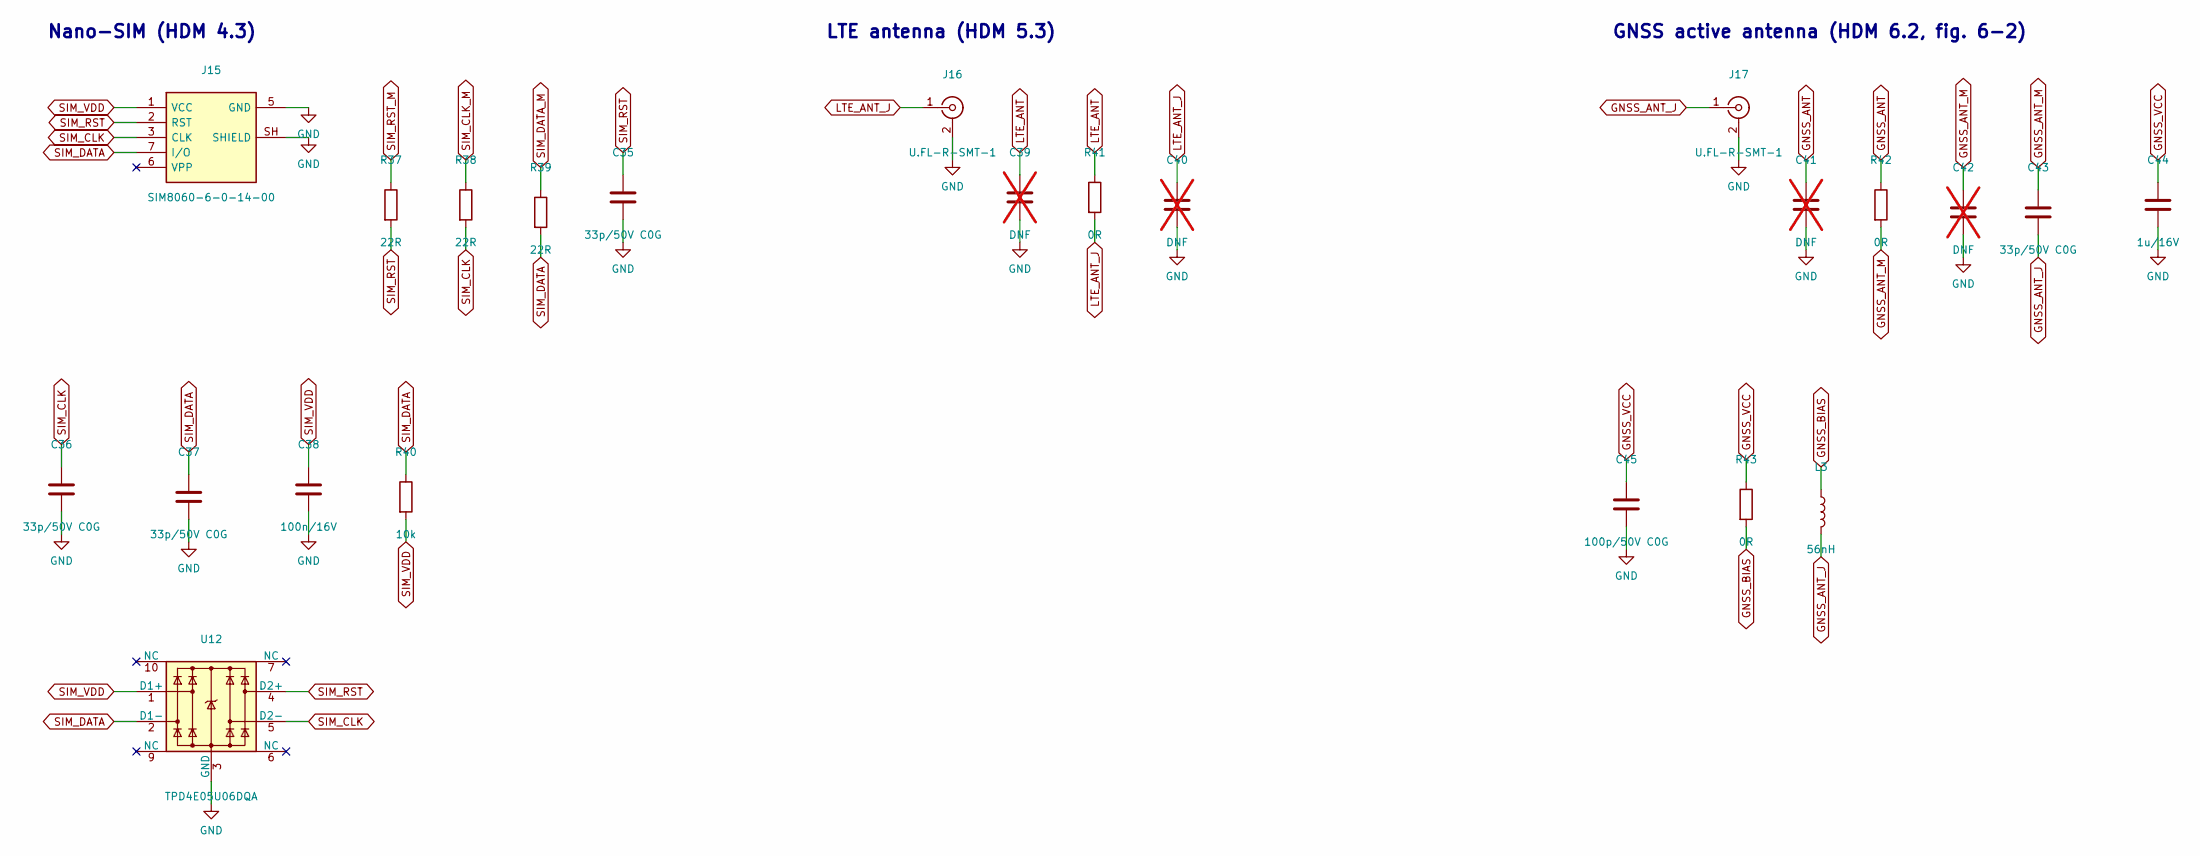
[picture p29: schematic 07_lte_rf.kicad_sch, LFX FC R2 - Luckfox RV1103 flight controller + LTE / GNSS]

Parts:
C35, C36, C37, C43: 33p/50V C0G; C_0402_1005Metric
C38: 100n/16V; C_0402_1005Metric
C39, C40, C41, C42: DNF; C_0402_1005Metric; not fitted
C44: 1u/16V; C_0402_1005Metric
C45: 100p/50V C0G; C_0402_1005Metric
J15: SIM8060-6-0-14-00; nanoSIM_GCT_SIM8060-6-0-14-00
J16, J17: U.FL-R-SMT-1; U.FL_Hirose_U.FL-R-SMT-1_Vertical
L3: 56nH; L_0402_1005Metric
R37, R38, R39: 22R; R_0402_1005Metric
R40: 10k; R_0402_1005Metric
R41, R42, R43: 0R; R_0402_1005Metric
U12: TPD4E05U06DQA; USON-10_2.5x1.0mm_P0.5mm

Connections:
GND: C35.2, C36.2, C37.2, C38.2, C39.2, C40.2, C41.2, C42.2, C44.2, C45.2, J15.5 (GND), J15.SH (SHIELD), J16.2 (Ext), J17.2 (Ext), U12.3 (GND), U12.8 (GND); also elsewhere on the board
GNSS_ANT: C41.1, R42.1; also elsewhere on the board
GNSS_ANT_J: C43.2, J17.1 (In), L3.2
GNSS_ANT_M: C42.1, C43.1, R42.2
GNSS_BIAS: L3.1, R43.2
GNSS_VCC: C44.1, C45.1, R43.1; also elsewhere on the board
LTE_ANT: C39.1, R41.1; also elsewhere on the board
LTE_ANT_J: C40.1, J16.1 (In), R41.2
SIM_CLK: C36.1, J15.3 (CLK), R38.2, U12.5 (D2-)
SIM_CLK_M: R38.1; also elsewhere on the board
SIM_DATA: C37.1, J15.7 (I/O), R39.2, R40.1, U12.2 (D1-)
SIM_DATA_M: R39.1; also elsewhere on the board
SIM_RST: C35.1, J15.2 (RST), R37.2, U12.4 (D2+)
SIM_RST_M: R37.1; also elsewhere on the board
SIM_VDD: C38.1, J15.1 (VCC), R40.2, U12.1 (D1+); also elsewhere on the board

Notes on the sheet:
Nano-SIM (HDM 4.3)
LTE antenna (HDM 5.3)
GNSS active antenna (HDM 6.2, fig. 6-2)

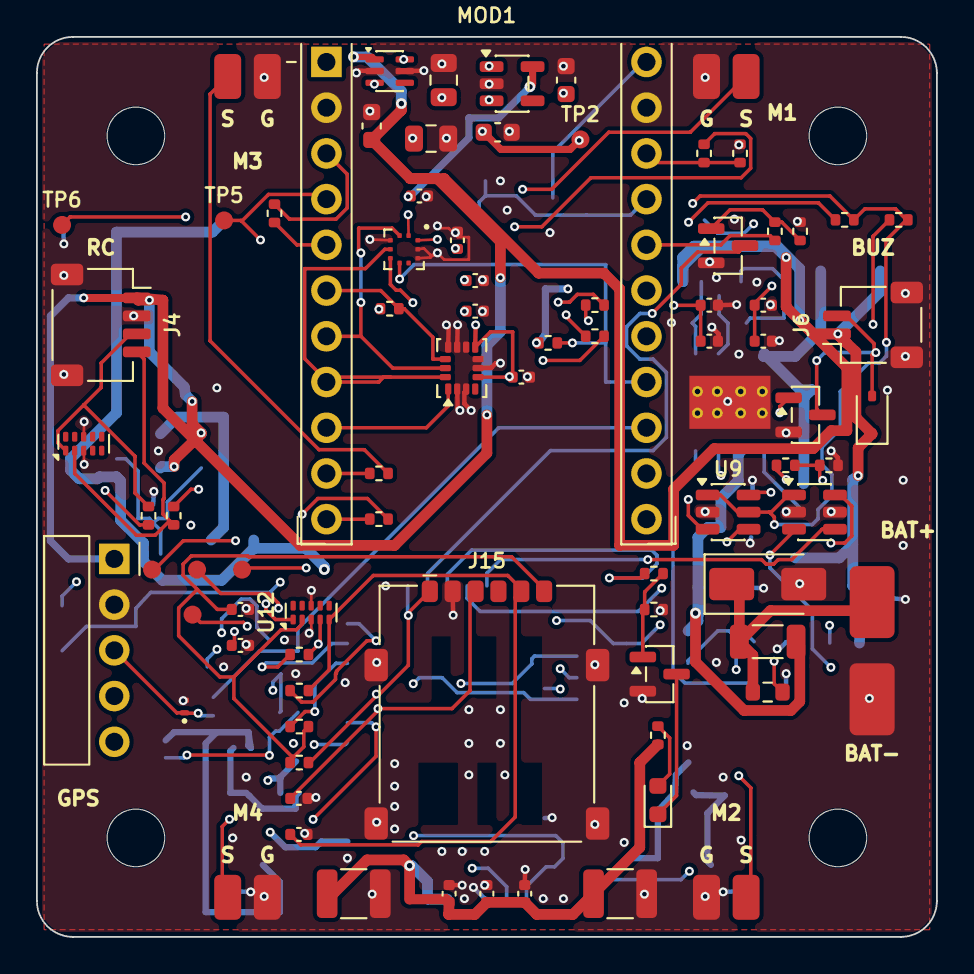
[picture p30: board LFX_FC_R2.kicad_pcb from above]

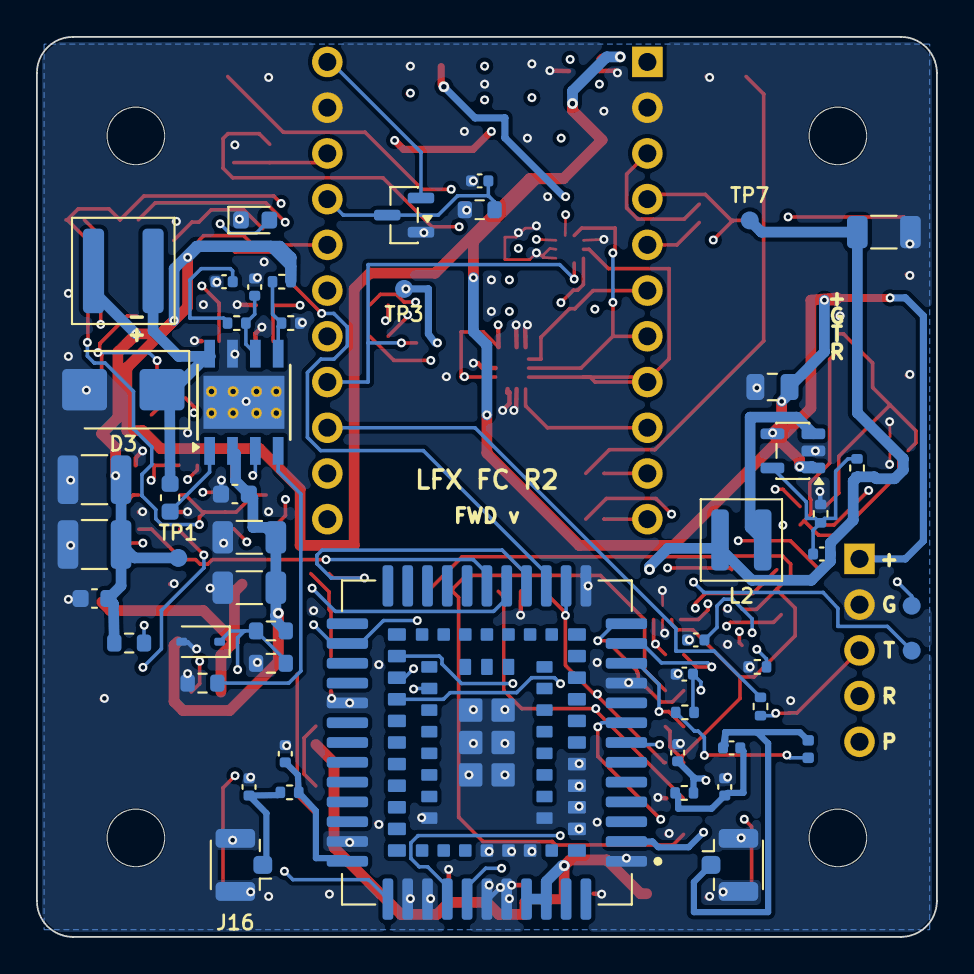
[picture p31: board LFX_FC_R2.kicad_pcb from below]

Board: 4 copper layers, 50.0 x 50.0 mm, 142 parts (52 on the bottom side), 76 nets.

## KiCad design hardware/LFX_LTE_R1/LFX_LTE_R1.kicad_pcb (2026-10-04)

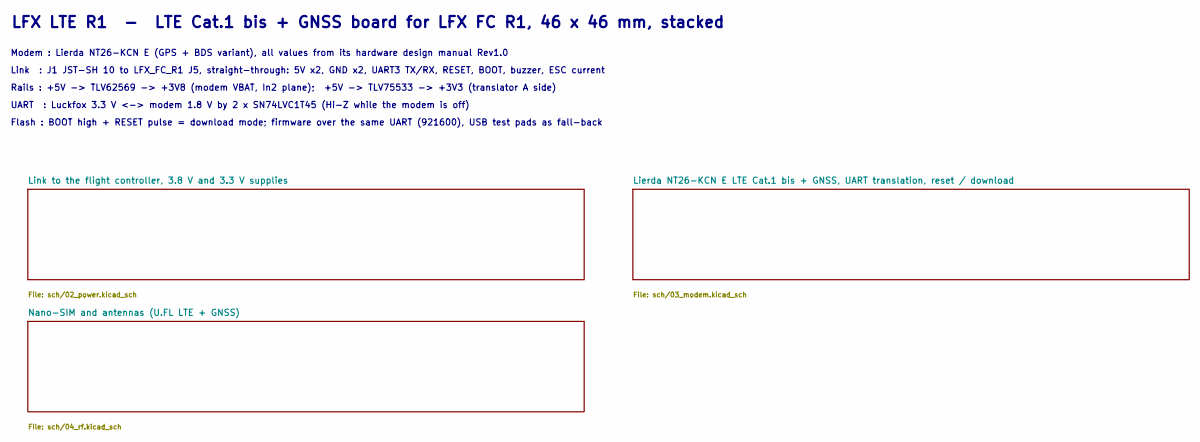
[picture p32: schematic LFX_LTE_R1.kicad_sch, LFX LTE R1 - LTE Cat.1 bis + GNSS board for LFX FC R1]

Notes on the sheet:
LFX LTE R1 - LTE Cat.1 bis + GNSS board for LFX FC R1, 46 x 46 mm, stacked
Modem : Lierda NT26-KCN E (GPS + BDS variant), all values from its hardware design manual Rev1.0
Link : J1 JST-SH 10 to LFX_FC_R1 J5, straight-through: 5V x2, GND x2, UART3 TX/RX, RESET, BOOT, buzzer, ESC current
Rails : +5V -> TLV62569 -> +3V8 (modem VBAT, In2 plane); +5V -> TLV75533 -> +3V3 (translator A side)
UART : Luckfox 3.3 V <-> modem 1.8 V by 2 x SN74LVC1T45 (Hi-Z while the modem is off)
Flash : BOOT high + RESET pulse = download mode; firmware over the same UART (921600), USB test pads as fall-back

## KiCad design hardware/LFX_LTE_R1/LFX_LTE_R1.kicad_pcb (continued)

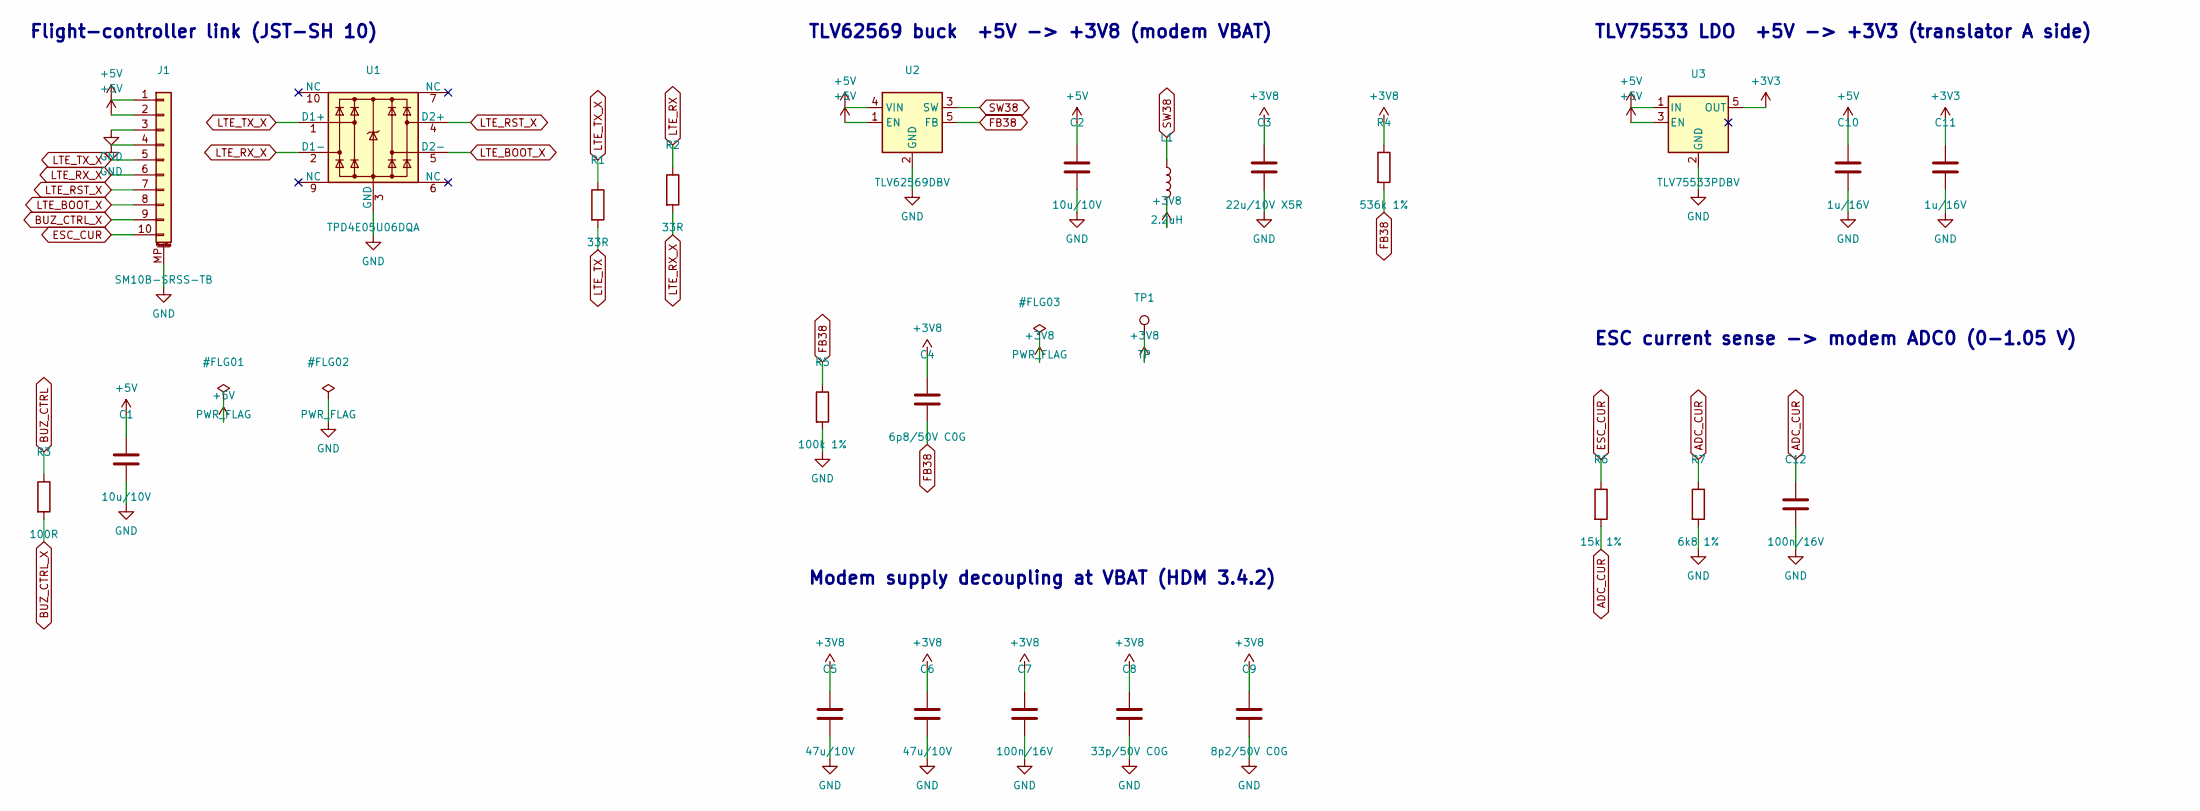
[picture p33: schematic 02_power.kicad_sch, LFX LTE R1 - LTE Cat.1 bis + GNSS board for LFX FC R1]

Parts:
C1, C2: 10u/10V; C_0805_2012Metric
C3: 22u/10V X5R; C_1206_3216Metric
C4: 6p8/50V C0G; C_0402_1005Metric
C5, C6: 47u/10V; C_1210_3225Metric
C7, C12: 100n/16V; C_0402_1005Metric
C8: 33p/50V C0G; C_0402_1005Metric
C9: 8p2/50V C0G; C_0402_1005Metric
C10, C11: 1u/16V; C_0603_1608Metric
J1: SM10B-SRSS-TB; JST_SH_SM10B-SRSS-TB_1x10-1MP_P1.00mm_Horizontal
L1: 2.2uH; L_Coilcraft_XAL4020-XXX
R1, R2: 33R; R_0402_1005Metric
R3: 100R; R_0402_1005Metric
R4: 536k 1%; R_0402_1005Metric
R5: 100k 1%; R_0402_1005Metric
R6: 15k 1%; R_0603_1608Metric
R7: 6k8 1%; R_0603_1608Metric
TP1: TP; TestPad_1.0mm
U1: TPD4E05U06DQA; USON-10_2.5x1.0mm_P0.5mm
U2: TLV62569DBV; SOT-23-5
U3: TLV75533PDBV; SOT-23-5

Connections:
+3V3: C11.1, U3.5 (OUT); also elsewhere on the board
+3V8: C3.1, C4.1, C5.1, C6.1, C7.1, C8.1, C9.1, L1.2, R4.1, TP1.1; also elsewhere on the board
+5V: C1.1, C2.1, C10.1, J1.1, J1.2, U2.1 (EN), U2.4 (VIN), U3.1 (IN), U3.3 (EN)
ADC_CUR: C12.1, R6.2, R7.1; also elsewhere on the board
BUZ_CTRL: R3.1; also elsewhere on the board
BUZ_CTRL_X: J1.9, R3.2
ESC_CUR: J1.10, R6.1
FB38: C4.2, R4.2, R5.1, U2.5 (FB)
GND: C1.2, C2.2, C3.2, C5.2, C6.2, C7.2, C8.2, C9.2, C10.2, C11.2, C12.2, J1.3, J1.4, J1.MP (MountPin), R5.2, R7.2, U1.3 (GND), U1.8 (GND), U2.2 (GND), U3.2 (GND); also elsewhere on the board
LTE_BOOT_X: J1.8, U1.5 (D2-); also elsewhere on the board
LTE_RST_X: J1.7, U1.4 (D2+); also elsewhere on the board
LTE_RX: R2.1; also elsewhere on the board
LTE_RX_X: J1.6, R2.2, U1.2 (D1-)
LTE_TX: R1.2; also elsewhere on the board
LTE_TX_X: J1.5, R1.1, U1.1 (D1+)
SW38: L1.1, U2.3 (SW)

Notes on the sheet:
Flight-controller link (JST-SH 10)
TLV62569 buck +5V -> +3V8 (modem VBAT)
Modem supply decoupling at VBAT (HDM 3.4.2)
TLV75533 LDO +5V -> +3V3 (translator A side)
ESC current sense -> modem ADC0 (0-1.05 V)

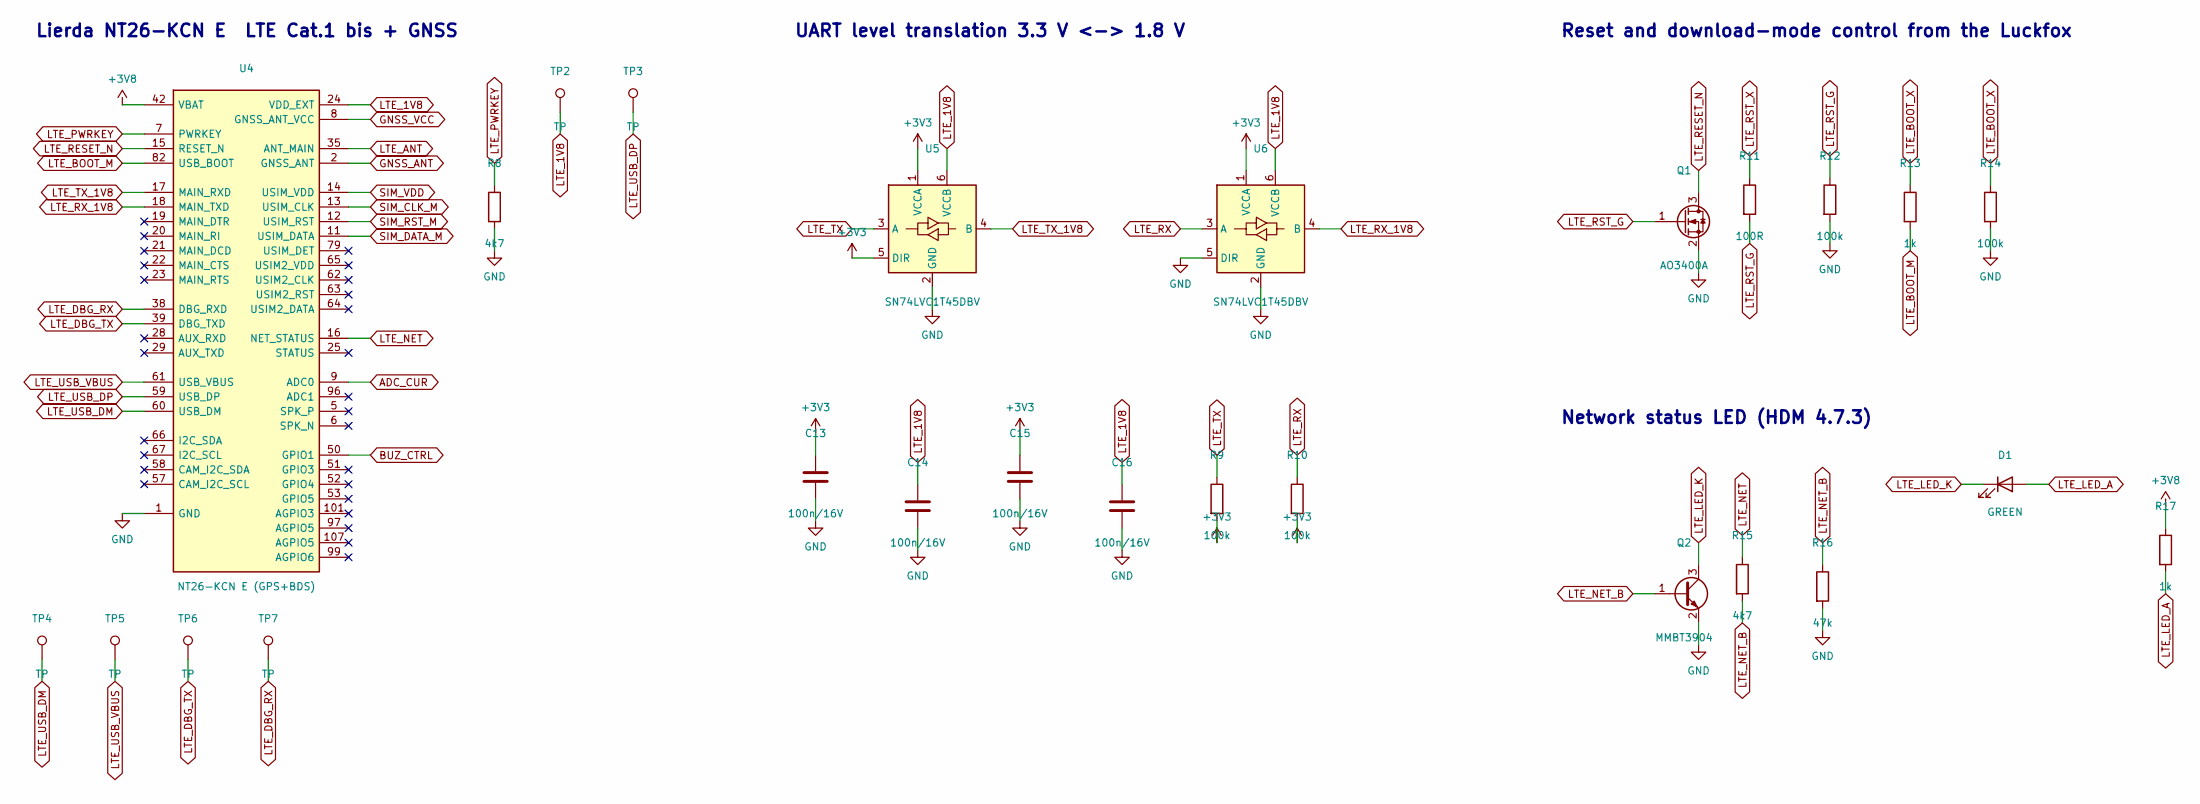
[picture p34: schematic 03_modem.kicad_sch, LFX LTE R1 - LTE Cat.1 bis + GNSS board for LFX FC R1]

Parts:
C13, C14, C15, C16: 100n/16V; C_0402_1005Metric
D1: GREEN; LED_0603_1608Metric
Q1: AO3400A; SOT-23
Q2: MMBT3904; SOT-23
R8, R15: 4k7; R_0402_1005Metric
R9, R10, R12, R14: 100k; R_0402_1005Metric
R11: 100R; R_0402_1005Metric
R13, R17: 1k; R_0402_1005Metric
R16: 47k; R_0402_1005Metric
TP2, TP3, TP4, TP5, TP6, TP7: TP; TestPad_1.0mm
U4: NT26-KCN E (GPS+BDS); Lierda_NT26-KCN_LCC-LGA-109_15.8x17.7mm
U5, U6: SN74LVC1T45DBV; SOT-23-6

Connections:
+3V3: C13.1, C15.1, R9.2, R10.2, U5.1 (VCCA), U5.5 (DIR), U6.1 (VCCA); also elsewhere on the board
+3V8: R17.1, U4.42 (VBAT), U4.43 (VBAT); also elsewhere on the board
ADC_CUR: U4.9 (ADC0); also elsewhere on the board
BUZ_CTRL: U4.50 (GPIO1); also elsewhere on the board
GND: C13.2, C14.2, C15.2, C16.2, Q1.2 (S), Q2.2 (E), R8.2, R12.2, R14.2, R16.2, U4.1 (GND), U4.10 (GND), U4.27 (GND), U4.34 (GND), U4.36 (GND), U4.37 (GND), U4.40 (GND), U4.41 (GND), U4.45 (GND), U4.46 (GND), U4.47 (GND), U4.48 (GND), U4.70 (GND), U4.71 (GND), U4.72 (GND), U4.73 (GND), U4.88 (GND), U4.89 (GND), U4.90 (GND), U4.91 (GND), U4.92 (GND), U4.93 (GND), U4.94 (GND), U4.95 (GND), U5.2 (GND), U6.2 (GND), U6.5 (DIR); also elsewhere on the board
GNSS_ANT: U4.2 (GNSS_ANT); also elsewhere on the board
GNSS_VCC: U4.8 (GNSS_ANT_VCC); also elsewhere on the board
LTE_1V8: C14.1, C16.1, TP2.1, U4.24 (VDD_EXT), U5.6 (VCCB), U6.6 (VCCB)
LTE_ANT: U4.35 (ANT_MAIN); also elsewhere on the board
LTE_BOOT_M: R13.2, U4.82 (USB_BOOT)
LTE_BOOT_X: R13.1, R14.1; also elsewhere on the board
LTE_DBG_RX: TP7.1, U4.38 (DBG_RXD)
LTE_DBG_TX: TP6.1, U4.39 (DBG_TXD)
LTE_LED_A: D1.2 (A), R17.2
LTE_LED_K: D1.1 (K), Q2.3 (C)
LTE_NET: R15.1, U4.16 (NET_STATUS)
LTE_NET_B: Q2.1 (B), R15.2, R16.1
LTE_PWRKEY: R8.1, U4.7 (PWRKEY)
LTE_RESET_N: Q1.3 (D), U4.15 (RESET_N)
LTE_RST_G: Q1.1 (G), R11.2, R12.1
LTE_RST_X: R11.1; also elsewhere on the board
LTE_RX: R10.1, U6.3 (A); also elsewhere on the board
LTE_RX_1V8: U4.18 (MAIN_TXD), U6.4 (B)
LTE_TX: R9.1, U5.3 (A); also elsewhere on the board
LTE_TX_1V8: U4.17 (MAIN_RXD), U5.4 (B)
LTE_USB_DM: TP4.1, U4.60 (USB_DM)
LTE_USB_DP: TP3.1, U4.59 (USB_DP)
LTE_USB_VBUS: TP5.1, U4.61 (USB_VBUS)
SIM_CLK_M: U4.13 (USIM_CLK); also elsewhere on the board
SIM_DATA_M: U4.11 (USIM_DATA); also elsewhere on the board
SIM_RST_M: U4.12 (USIM_RST); also elsewhere on the board
SIM_VDD: U4.14 (USIM_VDD); also elsewhere on the board

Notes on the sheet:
Lierda NT26-KCN E LTE Cat.1 bis + GNSS
UART level translation 3.3 V <-> 1.8 V
Reset and download-mode control from the Luckfox
Network status LED (HDM 4.7.3)


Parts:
C17, C18, C19, C25: 33p/50V C0G; C_0402_1005Metric
C20: 100n/16V; C_0402_1005Metric
C21, C22, C23, C24: DNF; C_0402_1005Metric; not fitted
C26: 1u/16V; C_0402_1005Metric
C27: 100p/50V C0G; C_0402_1005Metric
H1, H2, H3, H4: M3; MountingHole_3.2mm_M3
J2: SIM8060-6-0-14-00; nanoSIM_GCT_SIM8060-6-0-14-00
J3, J4: U.FL-R-SMT-1; U.FL_Hirose_U.FL-R-SMT-1_Vertical
L2: 56nH; L_0402_1005Metric
R18, R19, R20: 22R; R_0402_1005Metric
R21: 10k; R_0402_1005Metric
R22, R23, R24: 0R; R_0402_1005Metric
U7: TPD4E05U06DQA; USON-10_2.5x1.0mm_P0.5mm

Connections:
GND: C17.2, C18.2, C19.2, C20.2, C21.2, C22.2, C23.2, C24.2, C26.2, C27.2, J2.5 (GND), J2.SH (SHIELD), J3.2 (Ext), J4.2 (Ext), U7.3 (GND), U7.8 (GND); also elsewhere on the board
GNSS_ANT: C23.1, R23.1; also elsewhere on the board
GNSS_ANT_J: C25.2, J4.1 (In), L2.2
GNSS_ANT_M: C24.1, C25.1, R23.2
GNSS_BIAS: L2.1, R24.2
GNSS_VCC: C26.1, C27.1, R24.1; also elsewhere on the board
LTE_ANT: C21.1, R22.1; also elsewhere on the board
LTE_ANT_J: C22.1, J3.1 (In), R22.2
SIM_CLK: C18.1, J2.3 (CLK), R19.2, U7.2 (D1-)
SIM_CLK_M: R19.1; also elsewhere on the board
SIM_DATA: C19.1, J2.7 (I/O), R20.2, R21.1, U7.1 (D1+)
SIM_DATA_M: R20.1; also elsewhere on the board
SIM_RST: C17.1, J2.2 (RST), R18.2, U7.4 (D2+)
SIM_RST_M: R18.1; also elsewhere on the board
SIM_VDD: C20.1, J2.1 (VCC), R21.2, U7.5 (D2-); also elsewhere on the board

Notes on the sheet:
Nano-SIM (HDM 4.3)
LTE antenna (HDM 5.3)
GNSS active antenna (HDM 6.2, fig. 6-2)
Mounting


Board: 4 copper layers, 46.0 x 46.0 mm, 78 parts (0 on the bottom side), 46 nets.

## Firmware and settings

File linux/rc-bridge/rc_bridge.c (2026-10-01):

/*
 * rc-bridge: the drone's Linux side of remote control.
 *
 *   ELRS receiver --CRSF 420000 baud, UART2--+
 *                                           +--> pick a source --> fc_ipc "down" --> MCU
 *   ground station --CRSF frames over UDP--+
 *
 *   MCU --fc_ipc "up" telemetry--> CRSF frames --> ground station (UDP) and the
 *                                                  ELRS receiver (to the handset)
 *
 * Source rule: the ELRS receiver wins whenever it delivered a good frame in the last
 * --timeout-ms; otherwise the network; otherwise nothing is forwarded at all, and
 * the flight core's own RC timeout runs the failsafe (hold level, then land).  Stale
 * commands are never repeated: silence is the failsafe signal.
 *
 * Shared page: --devmem maps MCU_IPC_BASE through /dev/mem (on the board, the
 * reserved-memory page of shared/ipc/mcu_layout.h); --shm FILE maps a file (host,
 * with simulator/server.py --ipc FILE playing the MCU).
 * Builds for the board (SDK ARM toolchain, tools/build_linux_tools.sh) and the host.
 */
#include <arpa/inet.h>
#include <errno.h>
#include <fcntl.h>
#include <netinet/in.h>
#include <poll.h>
#include <signal.h>
#include <stdint.h>
#include <stdio.h>
#include <stdlib.h>
#include <string.h>
#include <sys/mman.h>
#include <sys/socket.h>
#include <time.h>
#include <unistd.h>

#include "../../shared/ipc/fc_ipc.h"
#include "../../shared/ipc/mcu_layout.h"
#include "../../shared/rc/crsf.h"
#include "uart.h"

static volatile sig_atomic_t g_stop;
static void on_signal(int s) { (void)s; g_stop = 1; }

static uint64_t now_ms(void)
{
    struct timespec ts;
    clock_gettime(CLOCK_MONOTONIC, &ts);
    return (uint64_t)ts.tv_sec * 1000u + (uint64_t)(ts.tv_nsec / 1000000);
}

static void *map_page(const char *shm, int devmem)
{
    int fd;
    off_t off = 0;
    if (devmem) {
        fd = open("/dev/mem", O_RDWR | O_SYNC);      /* uncached: no cache maintenance */
        off = (off_t)MCU_IPC_BASE;
    } else {
        fd = open(shm, O_RDWR | O_CREAT, 0644);
        if (fd >= 0 && ftruncate(fd, FC_IPC_PAGE_SIZE) < 0) {
            close(fd);
            fd = -1;
        }
    }
    if (fd < 0) {
        perror(devmem ? "/dev/mem" : shm);
        return NULL;
    }
    void *p = mmap(NULL, FC_IPC_PAGE_SIZE, PROT_READ | PROT_WRITE, MAP_SHARED, fd, off);
    close(fd);
    if (p == MAP_FAILED) {
        perror("mmap");
        return NULL;
    }
    return p;
}

static const char *mode_name(int mode, int state)
{
    if (state == 2 || state == 3)
        return "FAILSAFE";
    switch (mode) {
    case 0: return "ACRO";
    case 1: return "ANGLE";
    case 2: return "ALTHOLD";
    }
    return "?";
}

static void usage(void)
{
    fprintf(stderr,
            "usage: rc-bridge (--devmem | --shm FILE) [--uart DEV] [--baud N] [--udp PORT]\n"
            "                 [--timeout-ms N] [-v]\n"
            "  --devmem       shared page at MCU_IPC_BASE via /dev/mem (on the board)\n"
            "  --shm FILE     shared page in a file (host, with simulator/server.py --ipc FILE)\n"
            "  --uart DEV     ELRS receiver, e.g. /dev/ttyS2 (UART2 after the console moved)\n"
            "  --baud N       default 420000 (ExpressLRS default; TBS spec 416666)\n"
            "  --udp PORT     ground-station CRSF over UDP, default 7700\n"
            "  --timeout-ms N a source counts as live this long after its last frame, default 200\n");
}

int main(int argc, char **argv)
{
    const char *shm = NULL, *uart_dev = NULL;
    int devmem = 0, baud = 420000, udp_port = 7700, timeout_ms = 200, verbose = 0;
    for (int i = 1; i < argc; i++) {
        if (!strcmp(argv[i], "--devmem")) devmem = 1;
        else if (!strcmp(argv[i], "--shm") && i + 1 < argc) shm = argv[++i];
        else if (!strcmp(argv[i], "--uart") && i + 1 < argc) uart_dev = argv[++i];
        else if (!strcmp(argv[i], "--baud") && i + 1 < argc) baud = atoi(argv[++i]);
        else if (!strcmp(argv[i], "--udp") && i + 1 < argc) udp_port = atoi(argv[++i]);
        else if (!strcmp(argv[i], "--timeout-ms") && i + 1 < argc) timeout_ms = atoi(argv[++i]);
        else if (!strcmp(argv[i], "-v")) verbose = 1;
        else { usage(); return 2; }
    }
    if (!devmem && !shm) {
        usage();
        return 2;
    }
    signal(SIGINT, on_signal);
    signal(SIGTERM, on_signal);

    struct fc_ipc_port port;
    memset(&port, 0, sizeof(port));
    port.page = map_page(shm, devmem);
    if (!port.page)
        return 1;

    int ufd = -1;
    if (uart_dev && (ufd = uart_open(uart_dev, baud)) < 0) {
        fprintf(stderr, "rc-bridge: cannot open %s\n", uart_dev);
        return 1;
    }
    int sfd = socket(AF_INET, SOCK_DGRAM, 0);
    struct sockaddr_in a;
    memset(&a, 0, sizeof(a));
    a.sin_family = AF_INET;
    a.sin_port = htons((uint16_t)udp_port);
    a.sin_addr.s_addr = htonl(INADDR_ANY);
    if (sfd < 0 || bind(sfd, (struct sockaddr *)&a, sizeof(a)) < 0) {
        perror("udp");
        return 1;
    }
    fprintf(stderr, "rc-bridge: page %s, ELRS %s @ %d, ground station UDP %d\n",
            devmem ? "/dev/mem MCU_IPC_BASE" : shm, uart_dev ? uart_dev : "(none)", baud, udp_port);

    crsf_parser elrs, net;
    crsf_parser_init(&elrs);
    crsf_parser_init(&net);
    uint64_t t_elrs = 0, t_net = 0, t_hb = 0, t_gcs_tx = 0, t_uart_tx = 0, t_log = now_ms();
    struct sockaddr_in gcs;
    socklen_t gcs_len = 0;
    struct fc_ipc_telemetry tel;
    int have_tel = 0, uart_turn = 0, waiting_logged = 0;
    uint32_t fwd_elrs = 0, fwd_net = 0, tel_n = 0, hb_seq = 0;

    while (!g_stop) {
        struct pollfd pf[2];
        int n = 0;
        pf[n].fd = sfd; pf[n].events = POLLIN; n++;
        if (ufd >= 0) { pf[n].fd = ufd; pf[n].events = POLLIN; n++; }
        poll(pf, (nfds_t)n, 5);
        uint64_t now = now_ms();

        if (!fc_ipc_valid(&port)) {               /* MCU not up (or re-formatting) */
            if (!waiting_logged)
                fprintf(stderr, "rc-bridge: waiting for the MCU to format the shared page\n");
            waiting_logged = 1;
            usleep(20000);
            continue;
        }
        waiting_logged = 0;

        /* ---- ELRS receiver ---- */
        if (ufd >= 0 && (pf[1].revents & POLLIN)) {
            uint8_t buf[256];
            ssize_t r = read(ufd, buf, sizeof(buf));
            for (ssize_t i = 0; i < r; i++) {
                if (crsf_feed(&elrs, buf[i]) == CRSF_GOT_CHANNELS) {
                    t_elrs = now;
                    struct fc_ipc_rc rc;
                    memset(&rc, 0, sizeof(rc));
                    memcpy(rc.ch, elrs.channels, sizeof(rc.ch));
                    rc.source = FC_RC_ELRS;
                    rc.link_quality = elrs.link.up_lq;
                    rc.rssi_dbm = (int8_t)(-(int)elrs.link.up_rssi1);
                    fwd_elrs += fc_ipc_send(&port, &port.page->down, FC_IPC_RC, &rc, sizeof(rc));
                }
            }
        }

        /* ---- ground station ---- */
        if (pf[0].revents & POLLIN) {
            uint8_t buf[512];
            struct sockaddr_in from;
            socklen_t fl = sizeof(from);
            ssize_t r = recvfrom(sfd, buf, sizeof(buf), 0, (struct sockaddr *)&from, &fl);
            int got = 0;
            for (ssize_t i = 0; i < r; i++)
                if (crsf_feed(&net, buf[i]) == CRSF_GOT_CHANNELS)
                    got = 1;
            if (got) {
                gcs = from;
                gcs_len = fl;
                t_net = now;
                /* the receiver has priority: the network only flies when ELRS is silent */
                if (!t_elrs || now - t_elrs > (uint64_t)timeout_ms) {
                    struct fc_ipc_rc rc;
                    memset(&rc, 0, sizeof(rc));
                    memcpy(rc.ch, net.channels, sizeof(rc.ch));
                    rc.source = FC_RC_NETWORK;
                    fwd_net += fc_ipc_send(&port, &port.page->down, FC_IPC_RC, &rc, sizeof(rc));
                }
            }
        }

        /* ---- heartbeat, 10 Hz ---- */
        if (now - t_hb >= 100) {
            struct fc_ipc_heartbeat hb = {(uint32_t)now, hb_seq++};
            fc_ipc_send(&port, &port.page->down, FC_IPC_HEARTBEAT, &hb, sizeof(hb));
            port.page->linux_alive++;
            t_hb = now;
        }

        /* ---- telemetry from the MCU ---- */
        struct fc_ipc_record rec;
        while (fc_ipc_recv(&port, &port.page->up, &rec))
            if (rec.type == FC_IPC_TELEMETRY && rec.len >= sizeof(tel)) {
                memcpy(&tel, rec.payload, sizeof(tel));
                have_tel = 1;
                tel_n++;
            }
        uint8_t f[CRSF_MAX_FRAME];
        const float CD = 3.14159265f / 18000.0f;          /* centidegree -> rad */
        if (have_tel && gcs_len && now - t_gcs_tx >= 50) { /* 20 Hz to the ground */
            uint8_t pkt[3 * CRSF_MAX_FRAME];
            int len = crsf_pack_frame(CRSF_TYPE_LFX_STATUS, &tel, (int)sizeof(tel), pkt);
            len += crsf_pack_attitude(tel.pitch_cdeg * CD, tel.roll_cdeg * CD, tel.yaw_cdeg * CD,
                                      pkt + len);
            len += crsf_pack_flight_mode(mode_name(tel.mode, tel.state), pkt + len);
            sendto(sfd, pkt, (size_t)len, 0, (struct sockaddr *)&gcs, gcs_len);
            t_gcs_tx = now;
        }
        if (have_tel && ufd >= 0 && now - t_uart_tx >= 100) {   /* 10 Hz to the handset */
            int len = (uart_turn++ & 1)
                ? crsf_pack_flight_mode(mode_name(tel.mode, tel.state), f)
                : crsf_pack_attitude(tel.pitch_cdeg * CD, tel.roll_cdeg * CD, tel.yaw_cdeg * CD, f);
            if (write(ufd, f, (size_t)len) < 0 && errno != EAGAIN)
                perror("uart write");
            t_uart_tx = now;
        }

        if (now - t_log >= 5000) {
            const char *src = (t_elrs && now - t_elrs <= (uint64_t)timeout_ms) ? "ELRS"
                            : (t_net && now - t_net <= (uint64_t)timeout_ms) ? "network" : "NONE";
            fprintf(stderr, "rc-bridge: source %s | fwd elrs %u net %u | telemetry %u | "
                    "crc err elrs %u net %u | ipc crc %u\n", src, fwd_elrs, fwd_net, tel_n,
                    elrs.crc_errors, net.crc_errors, port.rx_crc_err);
            if (verbose && have_tel)
                fprintf(stderr, "  state %u mode %u h %d cm loop avg/max %u/%u us\n", tel.state,
                        tel.mode, tel.height_cm, tel.loop_us_avg, tel.loop_us_max);
            t_log = now;
        }
    }
    fprintf(stderr, "rc-bridge: stop\n");
    return 0;
}

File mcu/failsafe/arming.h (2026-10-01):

/*
 * Arming and failsafe state machine (plan sections 29 and 18-ish: "Never
 * enable ARMED motor output automatically after boot.  Default: DISARMED").
 *
 * Arming needs ALL of: a rising edge on the arm switch (a switch that is
 * already on at boot does nothing until it is cycled), throttle stick low,
 * a live RC link, a live IMU, a finished gyro calibration, and a nearly level
 * craft.  Disarm is immediate on the switch.
 *
 * Failsafe, in stages:
 *   RC lost > rc_timeout      stage 1: hold level, hold throttle, for
 *                             fs_hold_s (TBS: wait ~1 s before acting,
 *                             github.com/tbs-fpv/tbs-crsf-spec)
 *   still lost                stage 2: level, descend at fs_descent_rate
 *                             with the altitude estimate, or a fixed
 *                             fs_throttle without one; disarm when landed,
 *                             or when the time is up: fs_land_s plus the
 *                             time the descent itself needs from the height
 *                             at which the landing began (a fixed limit would
 *                             cut the motors in mid-air above ~14 m)
 *   IMU silent > imu_timeout  motors off at once (nothing to fly with)
 *   tilt > crash_tilt for crash_s while armed in a self-levelling mode:
 *                             motors off (crashed / flipped)
 * The link coming back during stage 1 hands control back; after stage 2 has
 * begun the pilot must disarm and re-arm.
 */
#ifndef ARMING_H
#define ARMING_H

#include <stdint.h>

typedef enum {
    FC_DISARMED = 0,
    FC_ARMED,
    FC_FAILSAFE_HOLD,
    FC_FAILSAFE_LAND,
} fc_state;

typedef enum {
    ARM_OK = 0,
    ARM_BLOCK_SWITCH_NOT_CYCLED = 1 << 0,
    ARM_BLOCK_THROTTLE = 1 << 1,
    ARM_BLOCK_RC = 1 << 2,
    ARM_BLOCK_IMU = 1 << 3,
    ARM_BLOCK_CALIB = 1 << 4,
    ARM_BLOCK_TILT = 1 << 5,
    ARM_BLOCK_FAILSAFE = 1 << 6,
} arm_block;

typedef enum {
    DISARM_NONE = 0,
    DISARM_SWITCH,
    DISARM_IMU_LOST,
    DISARM_CRASH,
    DISARM_FAILSAFE_LANDED,
    DISARM_FAILSAFE_TIMEOUT,
} disarm_reason;

typedef struct {
    float rc_timeout_s;
    float imu_timeout_s;
    float arm_max_tilt;        /* rad */
    float arm_max_throttle;    /* stick 0..1 */
    float fs_hold_s;
    float fs_land_s;
    float crash_tilt;          /* rad */
    float crash_s;
} arming_params;

typedef struct {
    int rc_ok, imu_ok, calib_ok;
    int arm_switch;            /* 0/1 */
    float throttle_stick;      /* 0..1 */
    float tilt;                /* rad from level */
    int landed;                /* from the controller's land detector */
    int crash_check;           /* 0 in ACRO: a flip is not a crash */
    float fs_descent_s;        /* time to descend from here (0 = height unknown) */
} arming_inputs;

typedef struct {
    arming_params p;
    fc_state state;
    int prev_switch;
    int switch_seen_off;       /* the switch has been off since boot/disarm */
    float rc_lost_s, imu_lost_s, crash_timer, fs_timer;
    float fs_budget;           /* landing time allowed, fixed when the landing began */
    uint32_t blocks;           /* why the last arm attempt (or now) is refused */
    disarm_reason last_disarm;
} arming_sm;

void arming_init(arming_sm *a, const arming_params *p);
/* dt in seconds; returns the new state */
fc_state arming_update(arming_sm *a, const arming_inputs *in, float dt);
const char *fc_state_name(fc_state s);

#endif

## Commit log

2026-09-24 01-rv1103-investigation: bang chung phan cung RV1103 va HPMCU tu SDK
    - SDK LuckfoxTECH/luckfox-pico main @ 824b817f
    - MCU: RISC-V SCR1 rv32imc 297 MHz, RT-Thread 3.1.3, boot qua SPL FIT standalone
    - vung MCU mac dinh 0x40000 nam trong kernel Linux (0x8000-0x78C364)
    - khong co RPMsg/UART MCU cho RV1106; loi tran timer.c:128
2026-09-24 02-stock-sdk-build: build firmware stock Luckfox Pico Mini B tren macOS
    run.sh: build trong Docker (OrbStack), flash bang rkdeveloptool, ket noi USB-ECM
2026-09-24 03-rtthread-build: build RT-Thread cho HPMCU bang luong build cua SDK
    - tools/build_mcu.sh: ./build.sh mcu <board>, ho tro doi vung link qua mcu_region.env
    - board hello world luckfox_mini-HELLO-NONE
2026-09-24 04-realtime-loop: firmware Milestone 1 va cong cu Linux (chua chay tren board)
    - mcu/bsp/luckfox_mini-M1-NONE: hello 1 s + vong lap 1 kHz, do chu ky/do tre/percentile
    - shared/ipc: mcu_layout.h (vung 0x01800000, de xuat), mcu_bench_shared.h
    - linux/mcu-tool: nap/dung MCU qua /dev/mem, doc log, ket qua, do clock
    - linux/dts: DTS Mini + reserved-memory; tools/install_m1.sh
2026-09-24 docs: so do chan Luckfox Pico Mini, cach noi UART2 debug
    - UART2 console: chan 4 (TX), 5 (RX), 115200, doi chieu rv1106-pinctrl.dtsi va rv1106.dtsi:1010
    - huong TX/RX cua UART4_M1 trong anh va DTS nguoc nhau
    - PWM tren header trung chan SPI0: con 3 kenh neu IMU dung SPI0
2026-09-24 fix(run.sh): build lai U-Boot + kernel khi chua co output/.run_sig
    Truoc day thieu chu ky thi coi nhu cau hinh khop, nen doi sang board M1
    (DTS khac) van giu boot.img stock.
2026-09-24 04-realtime-loop: MCU RT-Thread boot tren board, chay cung Linux
    - vung 0x01800000 kiem chung: DT reserved-memory, /proc/iomem, U-Boot relocate 0x03F80000
    - Linux ghi duoc HPMCU_BOOT_ADDR, mcu-tool load/stop chay
    - mcycle 297 000 180 Hz theo dong ho Linux; tick RT-Thread cham 0.1% (mtime chia DIV+1)
    - loi rkvenc timeout cua rkipc khong phu thuoc MCU (A/B 27/27 trong 30 s)
2026-09-24 04-realtime-loop: ket qua 1 000 000 vong 1 kHz duoi tai rkipc
    0 missed, 0 overrun; jitter max 116.7 us; P99.99 1099.75 us; latency ISR->thread avg 9.1 us, max 107 us
2026-09-24 04-realtime-loop: moc Linux idle, so sanh voi tai rkipc
    idle: jitter 18.2 us, P99.99 1013.0 us, latency max 15.1 us
    rkipc: jitter 116.7 us -> tai media Linux lam jitter MCU tang ~6.4 lan
2026-09-24 docs: kien truc phan cung va phan mem (sau Milestone 1)
    - phan chan: SPI0 IMU/baro (CS1 chan 14 theo DTS), PWM2 kenh 8-11 cho 4 ESC (chan 10,11,16,17), UART3 GPS
    - HAL MCU co I2C0-4, PWM0-2, UART0/2; khong co SPI
    - kernel khong co mailbox driver cho RV1106 -> IPC polling qua RAM chung
    - task MCU, tien trinh Linux, failsafe, rui ro, phuong an B
2026-09-24 hardware: LFX_FC_R1 schematic (Luckfox Pico Mini FC carrier)
    - 36x36 mm, 30.5 stack, 2S-6S via 4-in-1 ESC JST-SH 8
    - TPS54360 buck per TI SLVSBB4G fig. 34, UVLO recomputed for 2S (6.44/5.83 V)
    - LM66100 ideal diode: module ties USB-C VBUS to header pin 1
    - ICM-42688-P + BMP390 on SPI0, pinouts from TDK/Bosch datasheets
    - BMP390 footprint drawn from Bosch fig. 26 (stock ST HLGA-10 does not fit)
    - Luckfox socket footprint from the official STEP (rows 17.78 mm)
    - ERC 0 errors, 0 warnings
    [02_power.kicad_sch, 03_module.kicad_sch, 04_sensors.kicad_sch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]
2026-09-24 hardware: LFX_FC_R1 46x46 layout routed, DRC + parity clean
    - 46 x 46 mm, M3 NPTH holes in the corners (39 x 39 mm pattern),
    JST-SH connectors on the edges, ESC S/G solder pads at the four corners
    - IMU turned 90 deg so CS/SCK/MOSI/MISO face module pins 6..9 in order;
    the four lines are drawn (route_critical.hand_route_imu), not searched
    - via/track keep-outs under the IMU and barometer bodies, 0.5 mm routing
    keep-out round the board rim
    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
    [02_power.kicad_sch, 03_module.kicad_sch, 04_sensors.kicad_sch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]
2026-09-27 hardware: RC receiver port (ELRS/CRSF) on UART2 instead of debug console
    - J4 becomes a 4-pin JST-SH RC port: 1 5V, 2 GND, 3 TX (to receiver RX),
    4 RX (from receiver TX, CRSF 420000 baud), same order as the GPS port
    - R24 1k pull-up on RC_RX to the module's 3V3 (pin 3): ESP-based ELRS
    receivers stall in the bootloader if that line is low at power-up
    (expresslrs.org receiver wiring guide)
    - TP5/TP6 on RC_TX/RC_RX: console tap with the receiver unplugged
    - UART2 has its own fractional divider (clk-rv1106.c:441), 420000 x 16 =
    24 MHz x 7/25; not yet measured
    - docs: RC path goes through Linux, MCU failsafe on heartbeat loss; the
    console has to leave UART2 in software (fiq-debugger, ea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
    [03_module.kicad_sch, 04_sensors.kicad_sch, 05_io.kicad_sch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]
2026-09-27 05-simulator: flight core in portable C + SITL with 3D pilot view
    Flight core (mcu/, builds for host and later the rv32imc MCU, float only):
    - sensor_if: one interface for REAL_SENSOR and SIM_SENSOR (plan sec. 26)
    - gyro calibration at rest, accelerometer level calibration, biquad/PT1
    - Mahony attitude filter, baro + accel altitude filter
    - PID with clamp, anti-windup, D on measurement, I-term relax
    - cascade: rate 1 kHz, angle 250 Hz, altitude 100 Hz; ACRO/ANGLE/ALT_HOLD
    - quad-X mixer (board motor order M1 RR, M2 FR, M3 RL, M4 FL)
    - arming + failsafe: boots DISARMED, arm needs switch cycle + low throttle
    + RC + IMU + calibration + level; RC loss -> hold 1 s -> land -> disarm;
    IMU loss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
    [arming.h]
2026-09-27 05-simulator: flight core on the HPMCU (MCU simulation board)
    - mcu/bsp/luckfox_mini-FC-NONE: fc_tick() at 1 kHz on RT-Thread, fed by
    SIM_SENSOR and the quad model running on the MCU, pilot script through
    CRSF encode/parse; mcycle timing of fc_tick and quad_step, histogram,
    report to the RAM log every 5 s (plan section 29, step 2)
    - tools/build_mcu.sh copies the flight core into tree/ for boards that
    carry a FLIGHT_CORE marker, keeping the repository's include layout
    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
2026-09-27 docs: README with system block diagram, simulator screenshots and charts
    - README.md: status per milestone with evidence, architecture (Linux vs
    MCU ownership, control flow, risks), LFX_FC_R1 board (renders, specs,
    connector pinout), simulator gallery and test results, quick start for
    simulator / Linux firmware / MCU firmware / PCB pipeline, repo layout,
    safety sequence, doc index, sources
    - docs/img/system_block.svg: hand-drawn system block diagram, each block
    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
2026-09-27 publish: MIT + CERN-OHL-P licences, vendor documents out of the repo
    - LICENSE (MIT) for software and docs, hardware/LICENSE (CERN-OHL-P v2,
    official text from ohwr.org) for the hardware design
    - datasheets (TI, Bosch) and the Luckfox schematic are the vendors'
    copyright: no longer tracked; hardware/fetch_vendor.sh downloads them
    from the official URLs and makes the .txt copies with pdftotext;
    hardware/datasheets/README.md lists every source
    - t.pdf was a failed download (an HTML page), deleted
    - README: licence section, fetch step, no-warranty note
2026-09-27 05-simulator: fix "the drone won't fly" in the 3D page
    Found flying the page with real key events:
    - a crash latched the model with no word about it: big "crashed, press R"
    overlay; a coach line always says the next key to press
    - a clicked button kept focus, so Space toggled ARM and also "clicked"
    the button again (ARM on-off, or Reset fired): buttons drop focus and
    ignore Space/Enter
    - any connected gamepad-like device took the keyboard away for good: the
    pad now takes over only when a stick moves, a key hands control back
    - ALT_HOLD engaged while climbing locked the height of that instant, then
    overshot ~3 m and sank back: brake to |vz| < 0.3 m/s first, then lock
    (flight core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
    [fc_params.c, sim_cli.c]
2026-09-27 05-simulator: smooth 3D motion (fix the stutter while flying)
    Measured with a ?debug panel in a GPU headless Chrome (Apple M4, 60 fps):
    before, states reached the page every ~36 ms carrying 20-60 ms of sim
    time each (a 30 Hz sender beating against 50 Hz sim steps), and in 54 %
    of frames the flying craft did not move on screen, then jumped.
    - server.py: every sim step publishes one snapshot; /events sends each
    exactly once (50 Hz, +20 ms of sim time per state)
    - index.html: snapshot interpolation - render 80 ms behind the sim clock,
    lerp position / slerp attitude between the two states around that time;
    chase camera rigidly behind the craft with only the heading smoothed
    - ?debug panel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
2026-10-01 12-ipc + 13-remote: remote control over Linux, ground station with camera
    - shared/ipc/fc_ipc: Linux <-> MCU message channel in the reserved 4 KB
    page (MCU_IPC_BASE = the M1 benchmark page, no DTS change): two SPSC
    rings, seq + CRC-16, MCU-side D-cache clean/invalidate hooks
    - mcu/link/fc_link: RC records -> rc_map -> fc_rc_input, telemetry 50 Hz
    - linux/rc-bridge: ELRS receiver on UART (CRSF 420000, arbitrary baud via
    termios2 / IOSSIOSPEED) has priority over the ground station (CRSF over
    UDP 7700); stale commands are never repeated, silence = failsafe;
    telemetry as CRSF attitude / flight mode (+ private 0x7A status);
    builds for the board (ARM uClibc) and the host
    - ground/: gcs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
    [arming.h, fc.c, fc_bench.c]
2026-10-04 hardware: LFX_LTE_R1 stacked LTE + GNSS board, FC link on J5
    New 46 x 46 mm board hardware/LFX_LTE_R1 (same 39 mm M3 pattern, stacks on
    the flight controller, all parts on the top side):
    - Lierda NT26-KCN E LTE Cat.1 bis + GNSS (order the GPS + BDS variant);
    symbol and LCC/LGA-109 land pattern drawn from the Lierda hardware design
    manual Rev1.0 (table 2-5, fig. 2-2, fig. 8-3)
    - TLV62569 buck +5V -> 3.8 V (modem VBAT 3.3-4.5 V), In2 +3V8 plane,
    2 x 47 uF + 100n / 33p / 8p2 at VBAT; TLV75533 3.3 V for the translators
    - UART 3.3 <-> 1.8 V by 2 x SN74LVC1T45 (Hi-Z while the modem is off)
    - Luckfox reflashes the modem: RESET_N via AO3400A, USB_BOOT via 1k from the
    1.8 V BOOT pin; USB / de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
    [02_power.kicad_sch, 03_modem.kicad_sch, 03_module.kicad_sch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]
2026-10-04 hardware: LFX_MOUNT_R1 frame adapter plate, brushless + 4-ESC build guide
    - LFX_MOUNT_R1: 1.0 mm FR4 X plate (~1.7 g, generated by gen_mount.py):
    M3 on the boards' 39 x 39 mm pattern, M2 for 20 x 20 and 25.5 x 25.5 mm
    frame mounts, all on the two diagonals. DRC clean; the two M2 sets are
    alternatives, so their courtyard overlap is ignored for this holes-only
    board.
    - README: parts list for a 3" 2S brushless quad on LFX_FC_R1 with four
    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
    [LFX_MOUNT_R1.kicad_pcb]
2026-10-04 hardware: LFX_FC_R2 single 50x50 board with LTE/GNSS, FreeCAD frame + canopy
    LFX_FC_R2 (hardware/LFX_FC_R2) merges the flight controller and the LTE
    board onto one 50 x 50 mm, 4-layer board (M3 on 39 x 39 mm):
    - Lierda NT26-KCN E (GPS + BDS) under the front half, U.FL GNSS / LTE in
    the bottom front corners (50 ohm on B.Cu over In2 ground islands),
    hinged nano-SIM on top over it
    - Luckfox reflashes the modem: UART3 via SN74LVC1T45, RESET (pin 18),
    BOOT (pin 20); buzzer gate on the modem's AGPIO5
    - TPS54360 5 V buck bottom right, TLV62569 3.8 V modem buck bottom left
    - four separate ESCs on the corner S/G pads; 4-in-1 connector, the
    board-to-board cable and ESC current sense removed
    -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
    [02_power.kicad_sch, 03_module.kicad_sch, 04_sensors.kicad_sch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]
2026-10-05 hardware: LFX_FRAME_R1 for 1503 motors and 3.5" props
    - motor mounts: 22 mm pads, M2 slots r 4.3-6.6 mm (1503 9 x 9 mm square
    and 9 mm circle patterns), 7 mm centre hole
    - arms 5 mm x 13 mm; plate underside kept flat under the thicker arms
    - prop clearance search with a 3.5" disc: motors at 63 mm per axis,
    178 mm wheelbase, frame 148 x 148 mm, ~34 g PETG solid
    - README: parts for 1503 / 3.5" / 3S-4S, 20-30 A ESCs, weight estimate
    (~200 g on 4S), renders regenerated
    [frame.step, frame.stl]
2026-10-05 hardware: LFX_FC_R2 GPS port J18 (ATGM336H / NEO-M8N class) on UART5
    - J18: JST-SH 4-pin at the left edge, 1 +5V, 2 GND, 3 NC, 4 module TXD ->
    board RX. MOD1 pin 14 (GPIO1_D2) becomes UART5_RX_M1, 33R + TPD1E05U06 ESD.
    - Baro chip select moves to pin 15 (GPIO1_D3, MCU GPIO); IMU INT1 dropped
    (polled).
    - +5V to J18 hand-routed from J4 on B.Cu along the board edge (x 0.75), so it
    walls nothing in.
    - Hand routes for the connections the router kept leaving open: SIM RST/CLK
    (U12 channels swapped so they no longer cross), BUZ_CTRL, the U2 +5V
    escape, LTE_1V8 between U9/U10 (paths taken from dc53508).
    - gen_sch keeps the board rules in kicad_pro; clean_stubs removes dangling
    vias; Fre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
    [03_module.kicad_sch, 04_sensors.kicad_sch, 05_io.kicad_sch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]
2026-10-06 hardware: LFX_FC_R2 J18 as a 5-pin 2.54 mm header for the ATGM336H module
    The JST-SH 4 GPS port becomes a right-angle 1x05 header at the left edge,
    pin for pin with the 5-pin ATGM336H module (VCC GND TXD RXD PPS), so a
    straight Dupont lead plugs in. Module TXD goes to UART5_RX as before;
    RXD and PPS stay open (no Luckfox pins left).
    New LFX footprint PinHeader_1x05_P2.54mm_EdgeHorizontal (stock 3D model
    turned 180 degrees). Probe pads TP8/TP9 move to the bottom beside it.
    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
    [03_module.kicad_sch, 04_sensors.kicad_sch, 05_io.kicad_sch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]
